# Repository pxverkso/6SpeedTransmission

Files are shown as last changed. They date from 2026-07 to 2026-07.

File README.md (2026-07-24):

## Pxl Shift
---
# A Six Speed Transmission using 3 planetary gearboxes, this transmission was designed with First Tech Challenge hardware but can be adapted to the user's hardware. 
# All files are in .STEP and .STL format for easy editing of parts. The program code is in the .zip file called FTCRobotController.
  


## How it works
The Transmission has 6 different speeds that can be shifted automatically. Each stage takes around 5 seconds to ramp up to shifting speed. 

## Why I made this
This was a great CAD Exercise where I was able to practice my tolerances. It was also a learning opportunity for me to learn how transmissions work and how gears are able to be switched simultaneously.

The CAD Model of Pxl Shift is [Available Here](https://cad.onshape.com/documents/75fb335df3e2ec43449c259f/w/3389e1c426c2c39876040c3b/e/85c02890f00469d3cc6075b8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) for exporting, viewing or assembly. You don't need an account for Onshape to view assemblies. Please use this as the assembly instructions as well. 

## ASSEMBLY (IMPORTANT) 
I would explain the assembly process but it would end up being confusing for those of you actually building it since the part's all look similar so use the Onshape CAD. 
By looking at the left of your screen, you'll be able to see some folders of parts like the image below:



Then Click the Eye Button to hide the assembly. Like below




Hide All folders Except PG3 And Work Your way up in this File order:

PG3
PG2
PG1
Input Clutch
Base + Power Transmission
btrshftr

After You've build all the subsystems, you can just slide each subsystem into one another and it should assemble flawlessly. 

## Programming (If you'd like to motorize it)
For myself, I programmed my Pxl Shift on the 

## REV Robotics Control Hub 

A prebuilt PCB with preinstalled connectors and drivers, super easy to create projects like this for a programming newbie like me

An alternative PCB to this, if you want to build one yourself, is a Raspberry Pi with a Adafruit DC Motor Hat 
(Unfortunately you'll have to figure this out yourself, no code or drivers have been built for this project using these peripherals yet) 

My school let me borrow parts for this project and the parts I used can be easily substituted with much cheaper parts. Here are the parts list used in this [build](https://docs.google.com/spreadsheets/d/1n-YdPj7j1ZeOJgT02BMX6BGqi6td0hHqOzs9oTdzwKs/edit?usp=sharing)

Parts: (If you're worried about wires, if you order the motors from the website, wires are included in the package!)

| Link + Name | Price (Needed for build) USD | Price USD | Link | Total Price Needed for Build USD: | Column 5 | Total USD (Without Taxes): |
|:---|:---|:---|:-----|:---|:---|:---|
| 8mm REX Bearing | $99.73 (72) | $5.99 | https://www.gobilda.com/1611-series-flanged-ball-bearing-8mm-rex-id-x-14mm-od-5mm-thickness-2-pack/ | $857.96 | | $857.96 |
| REV Robotics Control Hub | $375 (1) | $375 | https://www.revrobotics.com/rev-31-1595/?searchid=5410248&search_query=control+hub | | | |
| 12v Nimh Battery | $64.99 (1) | $64.99 | https://www.gobilda.com/12v-nimh-nested-battery-3000mah-mh-fc-xt30-connector/ | Note: | | |
| Smart Robot Servo | $100.80 (4) | $25.20 | https://www.revrobotics.com/rev-41-1097/ | I built this using parts that | | |
| 8mm REX® Shaft with E-Clip (Stainless Steel, 216mm Length) | $8.29 (1) | $8.29 | https://www.gobilda.com/8mm-rex-shaft-with-e-clip-stainless-steel-216mm-length/ | were lent to me by my school | | |
| M4 Screws | $54.99 (1) | $54.99 | https://www.gobilda.com/m4-socket-head-screw-assortment-pack-600-pcs/ | I did not pay any of these prices | | |
| 8mm REX® Shaft with E-Clip (Stainless Steel, 168mm Length) | $7.19 (1) | $7.19 | https://www.gobilda.com/8mm-rex-shaft-with-e-clip-stainless-steel-168mm-length/ | I built this as an offseason | | |
| 2000 Series Dual Mode Servo (25-2, Torque) | $36.99 (1) | $36.99 | https://www.gobilda.com/2000-series-dual-mode-servo-25-2-torque/ | project to showcase at district | | |
| 5203 Series Yellow Jacket Planetary Gear Motor | $109.98 (2) | $54.99 | https://www.gobilda.com/5203-series-yellow-jacket-planetary-gear-motor-13-7-1-ratio-24mm-length-8mm-rex-shaft-435-rpm-3-3-5v-encoder/ | events. | | |

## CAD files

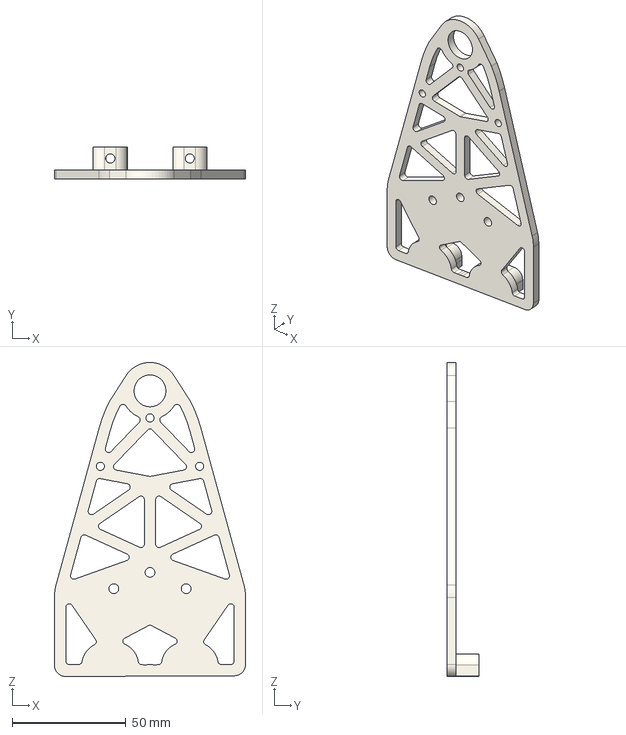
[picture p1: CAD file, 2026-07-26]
3D Printed Part STEP/3DP Base + Power Transmission Parts/Assembly 1 - Transmission Support Plate.step
84.1 x 14.0 x 138.1 mm

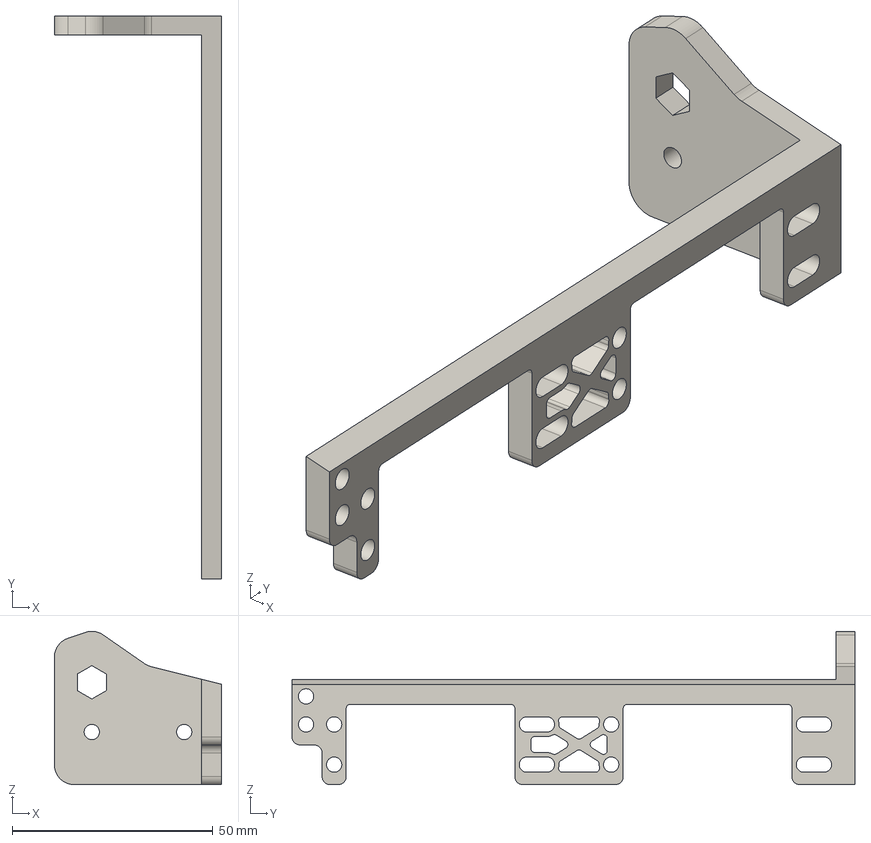
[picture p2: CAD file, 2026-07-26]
3D Printed Part STEP/3DP btrshftr Parts/Assembly 1 - btrshftr C1-C2 Shifter Plate Male.step
41.7 x 140.2 x 38.2 mm

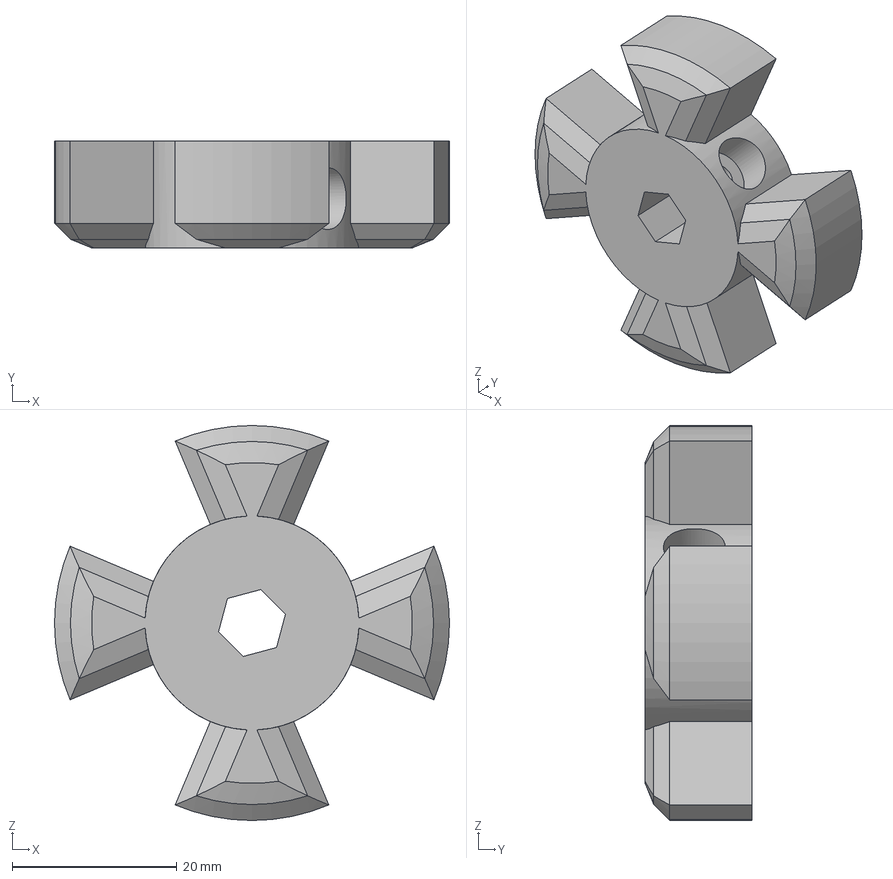
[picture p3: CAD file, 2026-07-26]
3D Printed Part STEP/3DP Input Clutch Parts/Assembly 1 - C1 Input Clutch.step
48.0 x 13.0 x 48.0 mm

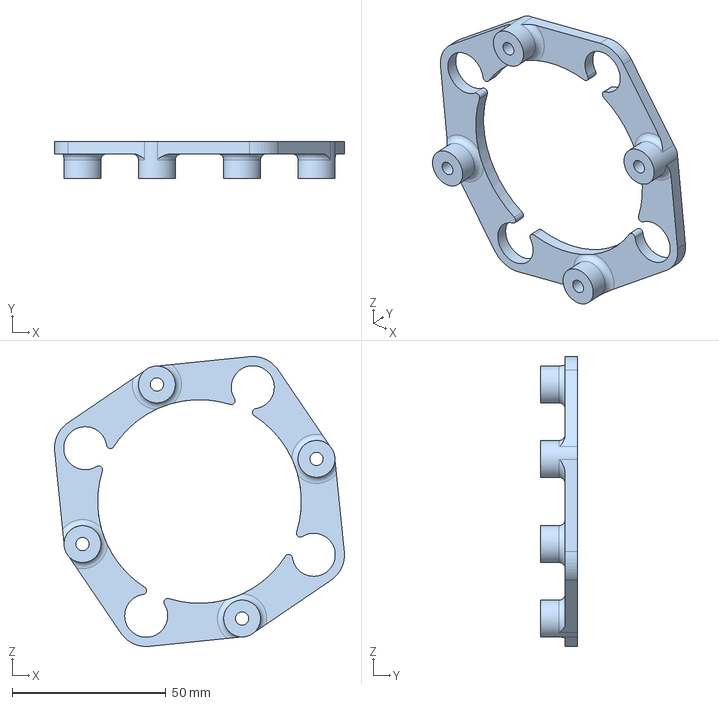
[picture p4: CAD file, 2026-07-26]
3D Printed Part STEP/3DP Planetary Gearbox 1 Parts/Assembly 1 - PG1 Carriage Male.step
94.3 x 12.0 x 94.3 mm

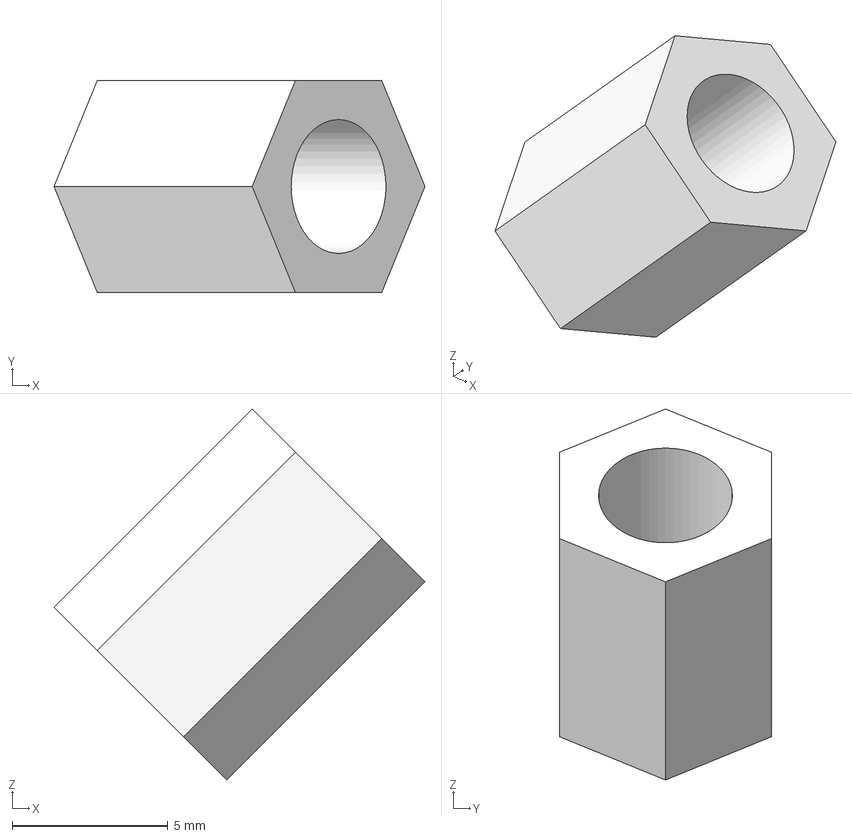
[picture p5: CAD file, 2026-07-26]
3D Printed Part STEP/3DP Planetary Gearbox 2 Parts/Assembly 1 - 9mm Bearing Axle.step
11.9 x 6.80 x 11.9 mm

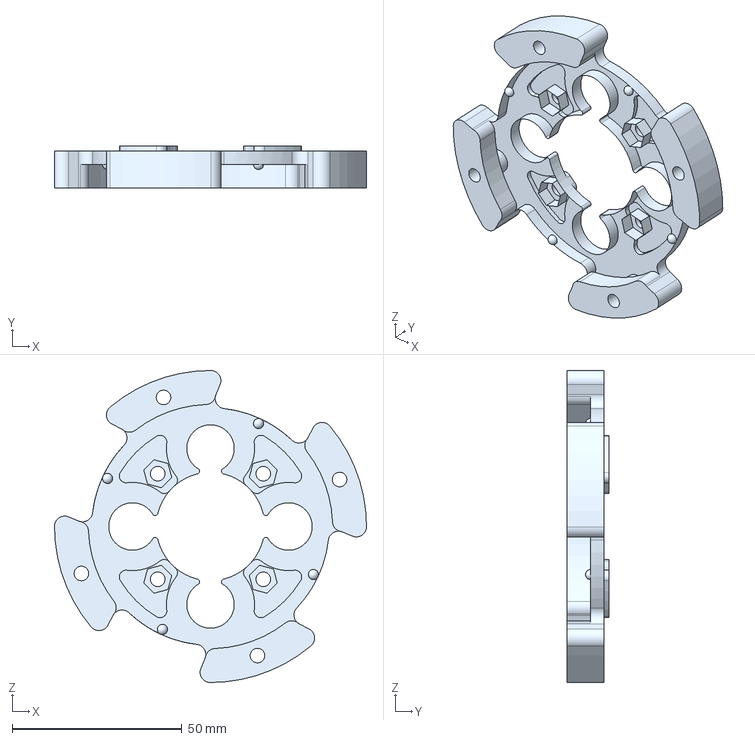
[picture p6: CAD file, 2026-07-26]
3D Printed Part STEP/3DP Planetary Gearbox 3 Parts/Assembly 1 - PG2 Carriage Male.step
92.0 x 12.5 x 92.0 mm

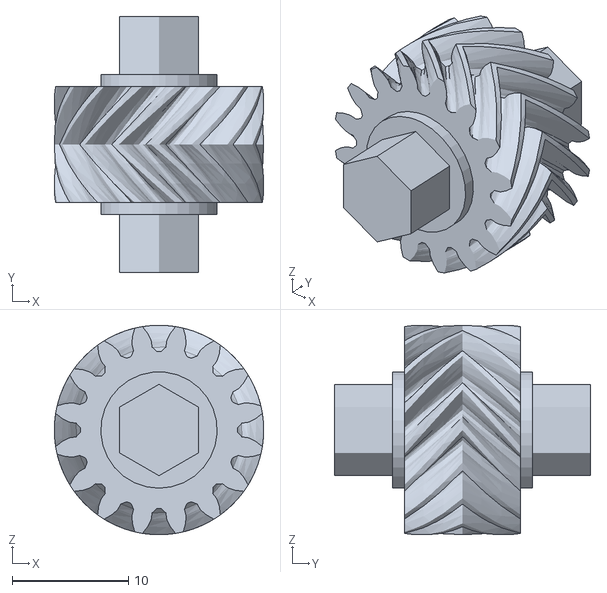
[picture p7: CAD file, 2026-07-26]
3D Printed Part STL/STL Base + Power Transmission Parts/Assembly 1 - Gearbox 16.stl
18.0 x 22.0 x 18.0

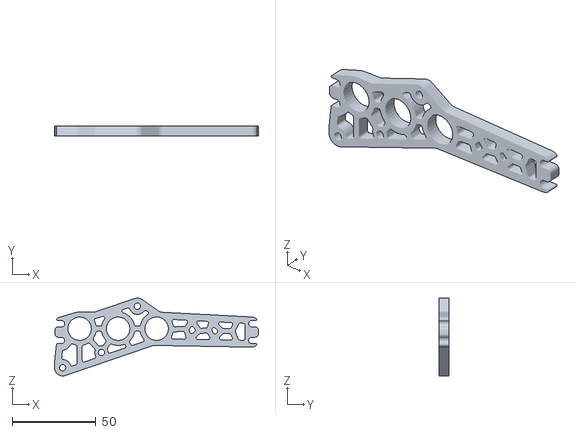
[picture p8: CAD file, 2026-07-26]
3D Printed Part STL/STL btrshftr Parts/Assembly 1 - btrshftr C3 Plate Female.stl
121.8 x 6.00 x 46.5

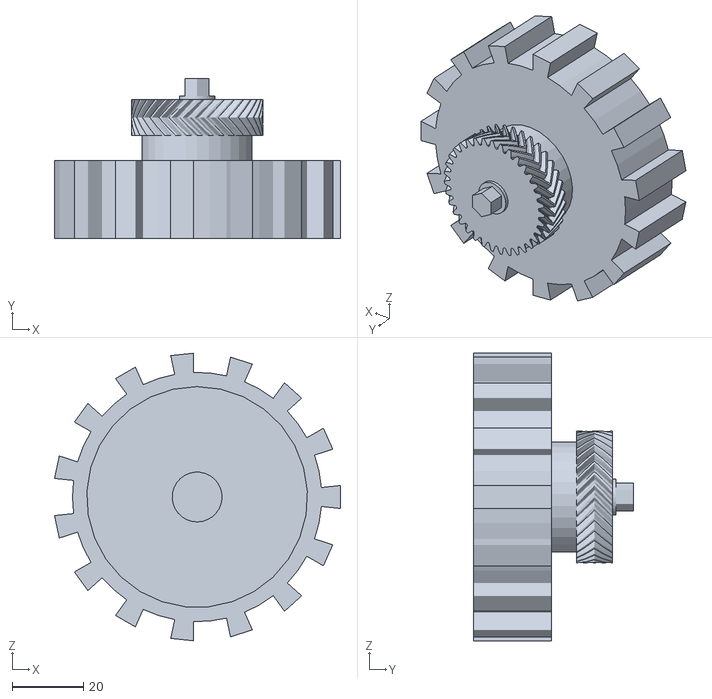
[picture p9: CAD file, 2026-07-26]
3D Printed Part STL/STL Input Clutch Parts/Assembly 1 - Input.stl
80.3 x 45.0 x 80.7

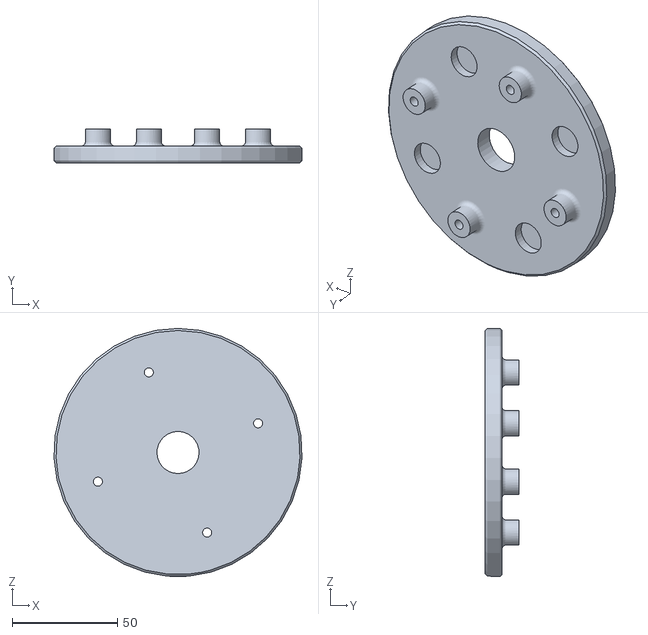
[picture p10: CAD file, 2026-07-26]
3D Printed Part STL/STL Planetary Gearbox 1 Parts/Assembly 1 - PG1 Carriage Female.stl
117.9 x 16.0 x 118.0

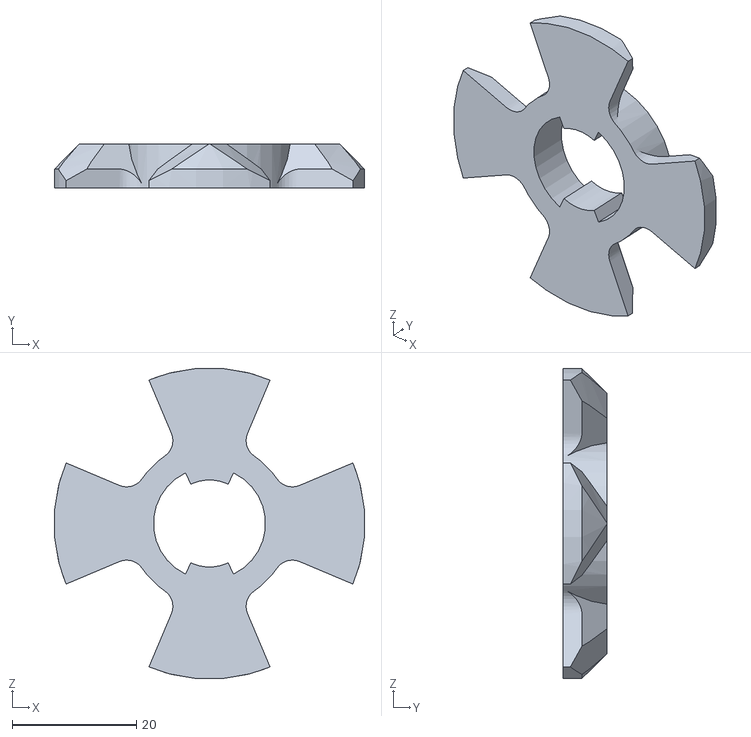
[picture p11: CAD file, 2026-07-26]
3D Printed Part STL/STL Planetary Gearbox 2 Parts/Assembly 1 - C2 Female.stl
49.8 x 7.00 x 49.8

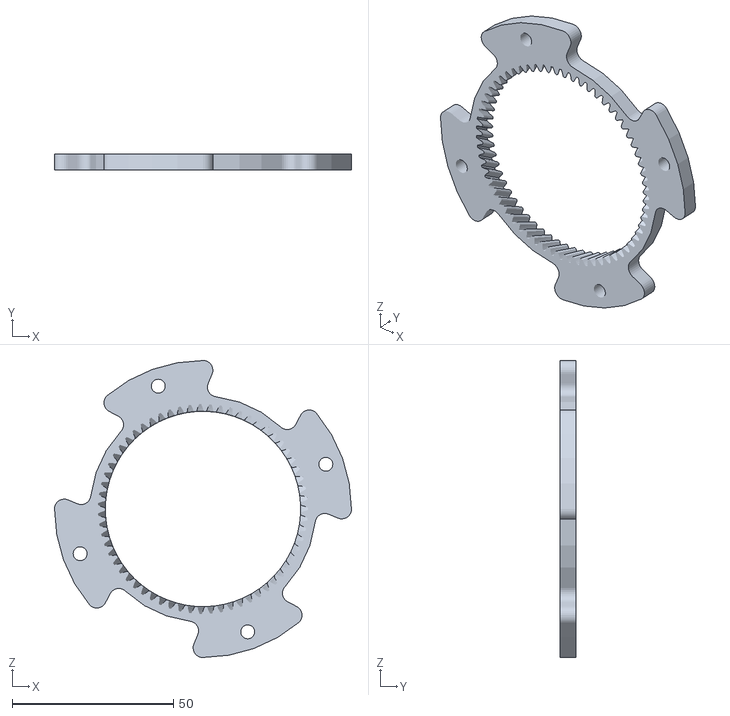
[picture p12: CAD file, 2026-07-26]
3D Printed Part STL/STL Planetary Gearbox 3 Parts/Assembly 1 - PG3 Ring 63.stl
92.0 x 5.00 x 92.0

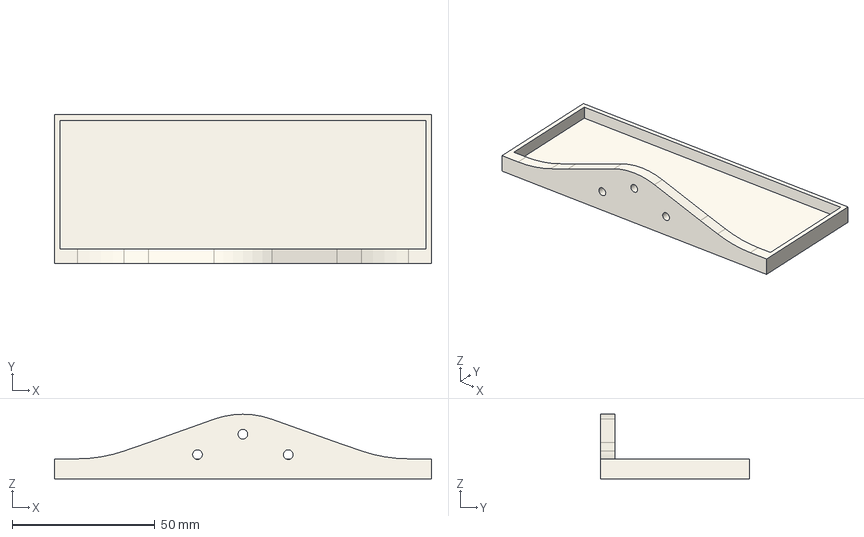
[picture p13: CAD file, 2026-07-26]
3D Printed Part STEP/3DP Base + Power Transmission Parts/Assembly 1 - Battery Mount.step
132.0 x 52.0 x 22.6 mm

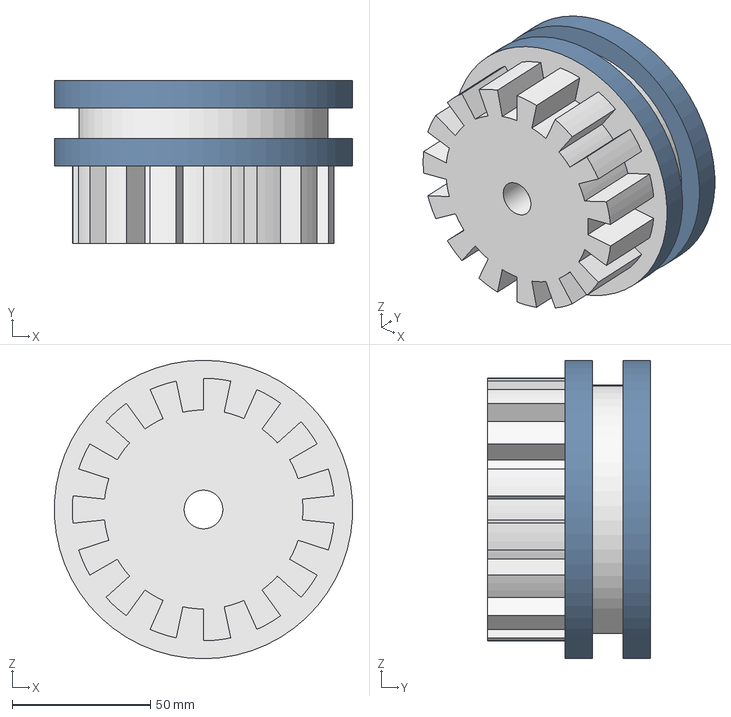
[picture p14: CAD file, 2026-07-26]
3D Printed Part STEP/3DP Input Clutch Parts/Assembly 1 - C1 Clutch.step
107.8 x 59.0 x 108.0 mm

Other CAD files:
3D Printed Part STEP/3DP btrshftr Parts/Assembly 1 - btrshftr C3 Plate Female.step
3D Printed Part STEP/3DP Planetary Gearbox 1 Parts/Assembly 1 - PG3 Ring 110.step
3D Printed Part STEP/3DP Planetary Gearbox 2 Parts/Assembly 1 - PG2 Planet 20.step
3D Printed Part STEP/3DP Planetary Gearbox 3 Parts/Assembly 1 - PG3 Ring 63.step
3D Printed Part STEP/3DP Base + Power Transmission Parts/Assembly 1 - Base.step
3D Printed Part STEP/3DP Base + Power Transmission Parts/Assembly 1 - Gearbox 16.step
3D Printed Part STEP/3DP Base + Power Transmission Parts/Assembly 1 - Gearbox Female.step
3D Printed Part STEP/3DP Base + Power Transmission Parts/Assembly 1 - Gearbox Gear Motor 16 (1).step
3D Printed Part STEP/3DP Base + Power Transmission Parts/Assembly 1 - Gearbox Gear Motor 16.step
3D Printed Part STEP/3DP Base + Power Transmission Parts/Assembly 1 - Gearbox Gear 2.step
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

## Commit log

2026-06-22 Update README with additional image and CAD link
    Added an additional image and repeated the CAD model link for clarity.
2026-06-22 Clarify file formats for parts editing and 3D printing
    Updated file formats mentioned for parts editing and rendering.
2026-06-23 added .STL files for parts
2026-06-24 Enhance README with assembly instructions and parts list
    Updated the README to clarify assembly instructions and parts list availability.
2026-07-24 Increase image sizes in assembly instructions
    Updated images to larger sizes for better visibility.
2026-07-26 Create STL
2026-07-26 Create Planetary Gearbox 3
